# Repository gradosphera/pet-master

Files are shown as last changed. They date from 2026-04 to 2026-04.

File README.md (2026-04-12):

# PET-Мастер

vlcsnap-2026-04-11-18h14m20s894

Образовательно-экологический проект по созданию настольного пултрузионного станка, который превращает использованные PET-бутылки в качественный филамент для 3D-печати.

Технология локальной переработки пластиковой тары в расходный материал для 3D-печати

[Паспорт проекта](/Паспорт%20проекта.md)
<br>
[Программа мастер-классов](/Программа%20мастер-классов.md)
<br>
[Технологическая карта](/Технологическая%20карта.md)
<br>
[Инструкция волонтера](/Инструкция%20волонтера.md)
<br>
[Протокол испытаний](/Протокол%20испытаний.md)
<br>
[Руководство по подбору ширины ленты](/Руководство%20по%20подбору%20ширины%20ленты.md)
<br>
[Регламент по технике безопасности](/Регламент%20по%20технике%20безопасности%20.md)
<br>
[Спецификация комплектующих](/Спецификация%20комплектующих.md)
<br>
[Список комплектующих](/Список%20комплектующих.md)
<br>
[Необходимый инструмент для сборки](/Необходимый%20инструмент%20для%20сборки.md)
<br>
[Схема электрическая принципиальная](/Схема%20электрическая%20принципиальная.md)

## 1. Резюме проекта

Проект «PET-Мастер» — это открытая образовательная и технологическая платформа, направленная на популяризацию вторичной переработки среди детей, школьников и студентов. Мы предлагаем доступную технологию создания настольного пултрузионного станка, который позволяет превращать использованные PET-бутылки в качественный филамент для 3D-принтера.

## 2. Актуальность и экологическая миссия

Ежегодно в мире производятся миллионы тонн PET-тары, лишь малая часть которой перерабатывается. 3D-печать, в свою очередь, требует дорогостоящего пластика.

«PET-Мастер» решает две задачи:

- Экология: Снижение количества мусора за счет локальной переработки пластика.
- Образование: Обучение основам инженерного дела, электроники и эко-осознанности через сборку реального устройства.

## 3. Описание технологии

В основе станка лежит метод термической пултрузии. В отличие от сложных промышленных шнековых экструдеров, используется упрощенная, но эффективная схема:

1.  Подготовка сырья: Бутылка очищается и нарезается на ленту шириной 6–10 мм.
2.  Термоформатирование: Лента проходит через нагретый до 210–220°C блок.
3.  Калибровка: Проходя через сопло диаметром 1.75 мм, плоская лента сворачивается в полую трубку, которая по физико-механическим свойствам идентична филаменту.
4.  Тяговый механизм: Червячный редуктор обеспечивает высокий крутящий момент и стабильную скорость протяжки, наматывая готовую нить на катушку.

## 4. Конструктив и концепция собери сам

Станок спроектирован по принципу открытых технологий: большая часть деталей корпуса изготавливается методом 3D-печати.

- Доступность компонентов: Все узлы (подшипники, нагреватели, контроллеры, метизы) доступны на популярных маркетплейсах.
- Формат документации: Чертежи и модели предоставляются в формате STL.
- Инструментарий: Для сборки требуется базовый набор: отвертки, гаечные и шестигранные ключи, паяльник, ножницы и кримпер для обжима контактов, дрель.

## 5. Образовательный потенциал

Проект является идеальным учебным пособием, охватывающим дисциплины:

- Аддитивные технологии: Понимание принципов работы FDM-печати.
- Схемотехника: Подключение PID-регуляторов, двигателей и блоков питания.
- Материаловедение: Изучение свойств полимеров (полиэтилентерефталат).
- Экологическое проектирование: Жизненный цикл продукта и экономика замкнутого цикла.

## 6. Технические характеристики (целевые)

- Тип сырья: ПЭТ-лента (из бутылок).
- Диаметр нити: 1.75 мм (допуск ±0.5 мм).
- Температурный режим: 210–220°C.
- Питание: 220В.
- Скорость производства: зависит от передаточного числа редуктора (в среднем 150–300 мм/мин).

## 7. Комплектация документации

Участники проекта получают доступ к полному пакету материалов:

1.  Спецификация на комплектующие.
2.  Набор STL-файлов для печати корпуса.
3.  Пошаговая инструкция по сборке и калибровке.
4.  Стандарты качества получаемой нити.

---

## Необходимый инструмент для сборки:

1.  Для механики: Набор отверток, гаечные ключи, шестигранные ключи.
2.  Для электрики: Паяльник, кримпер для обжима наконечников, ножницы.
3.  Для калибровки: Шуруповерт или дрель (для работы сверлом 1.7 мм по соплу).

## 📋 Таблица соединений на колодках

| Колодка | Вход | Выход / Потребитель |
| --- | --- | --- |
| №1 (AC 220V) | Сетевое гнездо + Кнопка | Вход Блока Питания 12В |
| №2 (DC 12V)  | Выход Блока Питания | ШИМ-контроллер, Вентилятор, Контроллер температуры |
| №3 (Нагрев)  | Реле контроллера температуры | Нагревательный элемент 50Вт |

## 💡 Важные рекомендации для сборки:

- Изоляция: Все соединения 220В должны быть закрыты термоусадкой или находиться внутри печатного корпуса, недоступного для случайного касания.
- Кримпер: Обязательно используйте обжим наконечников (НШВИ) перед фиксацией проводов в винтовых колодках — это предотвратит искрение и подгорание контактов.
- Полярность: У ШИМ-контроллера и термостата переполюсовка может привести к выходу из строя — проверяйте мультиметром «плюс» и «минус» перед включением.

## 7. Экономика и экологический эффект

## Расчет производственной мощности

Исходя из технических характеристик станка:

- Скорость переработки: 1 пластиковая бутылка (1,5 л) за 35 минут (среднее значение).
- Выход материала: 1 бутылка дает около 25–30 грамм качественного филамента.
- Годовой объем (при средней занятости): При работе станка всего 4 часа в день (учитывая время на сборку, отладку и подготовку ленты), проект позволяет перерабатывать около 2 500 бутылок в год.
- Итоговый продукт: Это эквивалентно 65–75 кг готового филамента для 3D-печати.

## Потенциальная выгода для местного сообщества

Локальная переработка на базе «PET-Мастера» превращает отходы в ценный ресурс:

1.  Экономия бюджета: Стоимость 75 кг заводского филамента составляет около 150 000 – 200 000 рублей. Проект позволяет сообществу (детскому дому, школе, фаблабу, ТСЖ) получать этот материал практически бесплатно.
2.  Стимул к раздельному сбору: Когда жители видят, как выброшенная бутылка превращается в полезную деталь (игрушку, инструмент, запчасть), ценность раздельного сбора становится осязаемой. Это формирует культуру «ноль отходов».
3.  Локальная очистка: Переработка 2 500 бутылок одним станком — это очистка территории небольшого парка или двора от видимого пластикового мусора в течение года.

## 8. Государственное и стратегическое значение

Проект «PET-Мастер» полностью соответствует вектору развития Российской Федерации:

- Национальный проект «Экологическое благополучие»: инициативы в сфере экономики замкнутого цикла.
- Цели-2030: Согласно государственным задачам, к 2030 году 100% твердых коммунальных отходов (ТКО) должны проходить сортировку, а не менее 25% — возвращаться в оборот как вторсырье. Наш проект является инструментом «низовой» цифровой экологии, позволяющим достигать этих показателей на уровне домохозяйств и образовательных центров.

## 9. Лицензирование и открытый доступ

Проект придерживается принципов открытого обмена знаниями:

- Документация и репозиторий: Текст «PET-Мастер», инструкции и схемы распространяются на условиях Общественного достояния (Public Domain). Любой человек или организация могут свободно использовать, копировать и распространять эти данные.
- 3D-модели корпуса: Файлы в формате STL распространяются под лицензией Creative Commons Некоммерческая (CC BY-NC).
- Разрешено: копировать, распространять, изменять и создавать производные работы.
  - Ограничение: использование моделей в коммерческих целях (продажа готовых станков или платных чертежей) запрещено. Это гарантирует, что проект останется доступным для образовательных и экологических сообществ.

---

PET-Мастер: Мы не просто перерабатываем пластик — мы печатаем будущее своими руками.
[Репозиторий проекта: https://github.com/gradosphera/pet-master

---

Лицензионное примечание: Данный документ является частью документации проекта «PET-Мастер» и распространяется на условиях Общественного достояния (Public Domain). Модели корпуса защищены лицензией CC BY-NC.

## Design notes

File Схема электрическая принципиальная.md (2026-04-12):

# Электрическая схема соединений станка

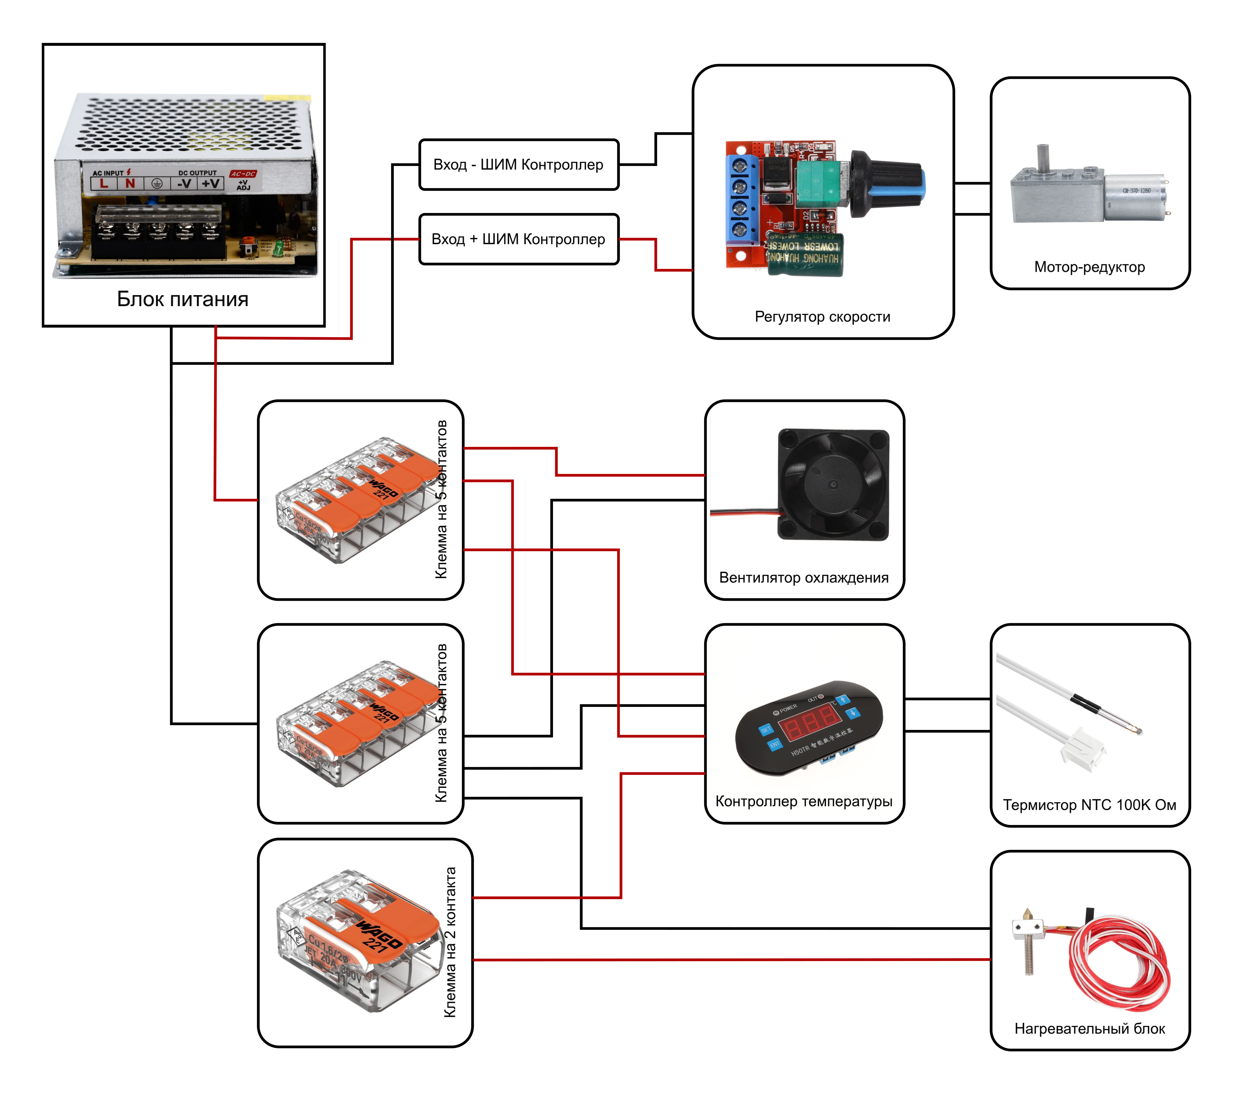
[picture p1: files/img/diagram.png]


```mermaid

flowchart
    %% Источник питания
    PSU[Блок питания 12В]

    %% Узлы распределения (Шины)
    PLUS{+ 12V}
    MINUS{- GND}

    PSU --> PLUS
    PSU --> MINUS

    %% Линия 1: Контроллер скорости и мотор
    subgraph Motor_Circuit [Линия мотора]
        PLUS --> PWM_IN_P[ШИМ Контроллер: Вход +]
        MINUS --> PWM_IN_M[ШИМ Контроллер: Вход -]
        PWM_IN_P --- PWM[Регулятор скорости]
        PWM_IN_M --- PWM
        PWM --> MOTOR[Мотор-редуктор]
    end

    %% Линия 2: Колодка и вентилятор
    subgraph Cooling_Circuit [Линия обдува]
        PLUS --> BUS_BAR[Электрическая колодка]
        BUS_BAR --> FAN_P[Вентилятор +]
        MINUS --> FAN_M[Вентилятор -]
    end

    %% Линия 3: Температурный контроль
    subgraph Heating_Circuit [Линия нагрева]
        %% Питание самого контроллера
        PLUS --> TEMP_POWER_P[Термоконтроллер: Питание +]
        MINUS --> TEMP_POWER_M[Термоконтроллер: Питание -]

        TEMP_POWER_P --- TEMP_CTRL[Контроллер температуры]
        TEMP_POWER_M --- TEMP_CTRL

        %% Цепь управления нагревом (Реле)
        PLUS --> RELAY_IN[Контакт реле K0]
        RELAY_IN --- RELAY[Реле контроллера]
        RELAY --- RELAY_OUT[Контакт реле K1]
        RELAY_OUT --> HEATER_P[Нагревательный модуль +]
        MINUS --> HEATER_M[Нагревательный модуль -]

        %% Датчик
        THERMISTOR[Терморезистор] --> TEMP_CTRL
    end

    %% Стилизация
    style PSU fill:#f9f,stroke:#333,stroke-width:4px
    style PLUS fill:#ff9999
    style MINUS fill:#9999ff
    style HEATER_P fill:#ff4444
    style MOTOR fill:#99ff99

```

## 1. Входная цепь (Сетевое напряжение 220В)

- Питание: Сетевой кабель C7 → Гнездо C8 на корпусе.
- Защита и разрыв: От гнезда C8 фазный провод идет на Тумблер (кнопку).
- Распределение: После кнопки провода (L и N) идут на Первую колодку (входную). К ней подключается вход вашего Блока Питания (БП) 12В.

## 2. Низковольтный блок (12В) — Распределение через клеммы

Выход с Блока Питания (+12В и -12В) подается на Вторую колодку (шину питания). Отсюда ток расходится на три узла:

А. Узел протяжки (Линия мотора):

1.  От 12В-колодки питание идет на вход ШИМ (PWM) контроллера (контакты Power+ / Power-).
2.  Выход ШИМ-контроллера (Motor+ / Motor-) подключается напрямую к Червячному мотор-редуктору.
3.  Примечание: Если вал крутится не в ту сторону, просто поменяйте провода мотора местами.

Б. Узел охлаждения:

1.  Вентилятор 40х40 подключается напрямую к 12В-колодке. Он должен работать постоянно при включении станка для охлаждения электроники и предотвращения расплавления корпуса.

В. Узел нагрева (Линия термостата):

1.  Питание 12В с колодки подается на контакты питания Контроллера температуры H50TR.
2.  Датчик температуры (Термистор NTC 100K) подключается в выделенный разъем на контроллере.
3.  Нагревательный блок: Один провод нагревателя идет к «+12В» на колодке, а второй — через Реле (выходные контакты) контроллера температуры к «-12В» (GND). Это позволит контроллеру разрывать цепь при достижении нужной температуры.

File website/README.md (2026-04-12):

# Сайт документации PET-Мастер

Репозиторий проекта: [github.com/gradosphera/pet-master](https://github.com/gradosphera/pet-master).

**Тема оформления:** в шапке кнопка переключает светлую и тёмную (фон `#1e2337`, зелёные акценты). Выбор сохраняется в `localStorage` (`pet-master-theme`).

## Локальный просмотр (папка `website/` внутри репозитория)

Из **корня** репозитория:

```bash
python -m http.server 8080
```

Откройте: [http://localhost:8080/website/](http://localhost:8080/website/)

Скрипт `js/pet-paths.js` сам подставляет префикс `../` к файлам репозитория (Markdown, CSV, `models/`, `docs/`, `models.zip`).

## GitHub Pages

1. В репозитории: **Settings → Pages → Build and deployment → Source: GitHub Actions**.
2. После push в ветку `main` запускается **Deploy GitHub Pages** (`.github/workflows/deploy-pages.yml`).
3. В корень публикации копируются: содержимое `website/`, все `*.md` из корня, `List_hardware_PET_Master.csv`, `models/`, `docs/`, при наличии — `files/`, а также **`models.zip`** (скрипт `scripts/zip-models.sh`).
4. Сайт: `https://gradosphera.github.io/pet-master/` (или `https://<org>.github.io/pet-master/` в зависимости от владельца).

Локально без подкаталога `/website/` пути **плоские** (`./README.md`, `./docs/...`) — так же работает опубликованная сборка.

## Фото процесса сборки (`files/img/Процесс сборки станка/`)

Сюда кладутся сюжетные **.webp** для страниц сайта (сборка, мастер-классы, работа станка). В HTML используется атрибут `data-pet-src` — URL подставляет `js/repo-links.js`.

## Превью 3D-деталей (`docs/img/`)

Таксономия совпадает с `models/`: **`docs/img/Основание/`**, **`docs/img/Электроника/`**, **`docs/img/Вал намотки/`**.

- Форматы: **`.jpg`** (основной), при отсутствии — **`.png`**.
- Имя файла обычно совпадает с моделью: расширение `.stl` / `.3mf` заменяется на `.jpg`. Для случаев вроде `…16 шт.stl` и `…16 шт..jpg` на странице перебираются варианты.
- В манифесте у категории поле **`imgFolder`** задаёт подкаталог в `docs/img/` (по умолчанию = `title`).
- У записи файла поле **`preview`**: имя файла в этой папке или полный путь `docs/img/…`.

## Архив моделей

```bash
bash scripts/zip-models.sh
```

Создаёт `models.zip` в корне репозитория (или путь первым аргументом). На GitHub Pages тот же архив кладётся в корень сайта; ссылка — на странице **3D-модели**.

## Обновление каталога STL

После добавления файлов в `models/` обновите `website/data/stl-manifest.json`.

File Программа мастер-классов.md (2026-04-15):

# Программа мастер-классов «PET-Мастер: От бутылки до значка»

Цель: Обучение полному циклу рециклинга ПЭТ и популяризация раздельного сбора.
Длительность: 4 занятия по 1.5–2 часа.
Бонусы: Именные значки из «мусора», верифицированные часы на Добро.РФ.

---

## Занятие 1: «Эко-логика и подготовка сырья»

- Теория (20 мин): Проблема ПЭТ в России. Экономика замкнутого цикла. Национальные цели 2030. Разница между PET, HDPE и другими видами пластика.
- Практика (60 мин):
- Сортировка принесенной тары.
- Удаление клея и этикеток.
- Рифтовка: Накачка бутылок через ниппель и выравнивание строительным феном.
- Результат: Подготовленные «ровные» заготовки для нарезки.

## Занятие 2: «Инженерия станка и нарезка ленты»

- Теория (20 мин): Устройство станка «PET-Мастер». Зачем нужен червячный редуктор? Как работает термоконтроллер H50TR.
- Практика (60 мин):
- Измерение толщины стенок бутылок штангенциркулем.
- Настройка встроенного ножа (подбор калибровочных дисков).
- Нарезка ленты (каждый волонтер должен подготовить моток 10–15 метров).
- Результат: Моток ленты, готовый к экструзии.

## Занятие 3: «Экструзия и управление качеством»

- Теория (15 мин): Физика процесса пултрузии. Почему ПЭТ из бутылок тугоплавкий? Разбор ГОСТ Р 59100-2020.
- Практика (70 мин):
- Разогрев станка до 215°C.
- Заправка ленты и запуск мотора.
- Контроль диаметра нити (заполнение протокола испытаний).
- Результат: Катушка готового вторичного филамента.

## Занятие 4: «3D-печать и награждение»

- Теория (15 мин): Настройка слайсера для печати ПЭТ-лентой. Коэффициент потока 130% и высокие температуры (260°C).
- Практика (60 мин):
- Запуск печати значков проекта (логотипы «Зеленый дом» или «Лаборатория переработки»).
- Наблюдение за процессом, разбор типичных ошибок печати.
- Финал (15 мин):
- Вручение значков, напечатанных на глазах волонтеров.
- Проставление волонтерских часов в системе Добро.РФ (через личный кабинет организатора).

---

## Инструкция по Добро.РФ:

1.  Создание мероприятия: Название «Мастер-класс по вторичной переработке ПЭТ-тары».
2.  Тип волонтерства: «Экологическое» или «Научное».
3.  Описание вклада: «Участие в производстве вторичного сырья для аддитивных технологий и ликвидация пластикового загрязнения».
4.  Подтверждение: После занятия организатор сканирует QR-код волонтера или вводит ID для начисления часов.

---

## Оборудование для одного учебного места:

- Станок «PET-Мастер» — 1 шт.
- Строительный фен и насос — 1 шт.
- Штангенциркуль — 1 шт.
- 3D-принтер (с цельнометаллическим хотэндом) — 1 шт. на группу.
- Индивидуальные средства защиты (перчатки).

---

# Программа мастер-классов «PET-Инженер: Мастерская вторичной переработки»

Цель: Сборка 3-х действующих станков (PET-Мастер) для масштабирования проекта и обучения инженерным навыкам.

Срок реализации: 4 недели (1 занятие в неделю по 2-2.5 часа + самостоятельная работа).

Место: МОУ "Инженерная школа города Комсомольска-на-Амуре"

Бонусы: Верифицированные часы на Добро.РФ, статус «PET-Инженер».

## Календарный план занятий

| Неделя | Тема занятия | Основные задачи | Результат этапа |
| --- | --- | --- | --- |
| 1 | Архитектура и электроника | Разбор схем управления (Терморегулятор/Контроллер), пайка, сборка нагревательного блока и датчиков. | Собранный электронный модуль управления. |
| 2 | Механика и 3D-печать | Сборка рамы станка, установка мотор-редуктора. Обсуждение параметров печати деталей. | Сборка корпуса станка. |
| 3 | Протяжка и термоблок | Монтаж сопла, системы нарезки ленты и механизма крепления нити на барабан. Настройка температуры. | Готовая конструкция, готовая к первым тестам. |
| 4 | Калибровка и запуск | Настройка стабильности диаметра нити (1.75 мм), тестовая печать значков из полученного филамента. | 3 готовых станка, переданые в дар школе. |

---

## Ресурсная спецификация (на 3 станка)

Для реализации программы требуется предварительная подготовка в МОУ "Инженерная школа города Комсомольска-на-Амуре":

- 3D-печать комплектующих:
- Время: ~20 часов суммарно.
  - Материал: ~2 кг пластика (рекомендуется PETG для деталей корпуса).
- Электронная база: Цифровые терморегуляторы H50TR, , нагревательные блоки 50W, термисторы, ШИМ-контроллеры, блоки питания 12V.
- Механическая база: Мотор-редукторы 12V 6 об. мин., Сопла (диаметр 0.6 мм), подшипники, профиль 30x30

---

## Методические особенности (Инженерная школа №25)

1.  Интеграция с Инженерной Школой: Школьники могут самостоятельно собрать или доработать станки.
2.  Масштабируемость: Каждый собранный станок становится «производственной единицей» для других школ города.
3.  Практический выход: Ученики школы №25 выступают в роли инженеров-производителей, обеспечивая оборудованием новые площадки проекта «PET-Мастер».

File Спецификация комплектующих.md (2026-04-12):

# Спецификация комплектующих (BOM-лист) проекта «PET-Мастер»

## 1. Электроника и управление нагревом

- Контроллер температуры H50TR (-40~300℃) — 1 шт. (основной блок управления нагревом).
- Нагревательный блок 12В 50Вт (6х20мм) — 1 шт. (элемент для плавления ленты).
- Термистор NTC 100K Ом 3950 (разъем XH2.54-2P) — 1 шт. (датчик температуры).
- ШИМ (PWM) контроллер 5A 90Вт 12В (XK-1074) — 1 шт. (регулировка скорости протяжки).

## 2. Механика и привод

- Червячный мотор-редуктор 12В (8 мм вал, 6 об/мин) — 1 шт. (силовой агрегат тяги).
- Подшипник 608Z — 2 шт. (для плавного вращения катушки/вал).
- Профиль конструкционный алюминиевый 30х30H (300мм) — 2 шт. (основа рамы станка).

## 3. Электрика и коммутация

- Гнездо питания C8 сетевое (10А) — 1 шт. (вход питания на корпусе).
- Сетевой кабель питания С7 (1,5м) — 1 шт. (шнур в розетку).
- Вилка угловая 16А — 1 шт.
- Провод ПВС 3х1,5 — 1 метр.
- Клеммы быстрозажимные (Wago-тип): 2 контакта (1 шт.), 5 контактов (2 шт.).
- Колодка винтовая КЭВ 3-12 (12 пар) — 1 шт.
- Тумблер-кнопка круглый (3А, 16мм) — 1 шт. (включение устройства).
- Вентилятор 40х40х20 12В — 1 шт. (охлаждение электроники и зоны выхода нити).

## 4. Расходники для экструзии

- Сопло латунное 0.6 мм — 3 шт. (используются как эструдер; рассверливаются до 1.75 мм).
- Сверло по металлу 1.7 мм (кобальтовое) — 1 шт. (для калибровки сопла).
- Пластик для 3D-принтера (1кг) — 1 шт. (для печати деталей самого станка).

## 5. Крепежные изделия (Метизы)

- Болты М8: М8х200 (2 шт.), М8х35 (2 шт.), М8х40 (4 шт.).
- Винт специальный: M8x8x120мм (цилиндрическая головка) — 1 шт.
- Винты М3: М3х10 (10 шт.), М3х12 (10 шт.), М3х16 (5 шт.).
- Гайки: М3 (20 шт.), М8 (3 шт.).
- Шайбы: М8 оцинкованные (4 шт.).
- Пластина соединительная 2мм (40х100) — 1 шт. (усиление конструкции).

## 6. Прочее и СИЗ

- Колодка 4м 16Д (3,5кВт) — 1 шт.
- Перчатки трикотажные — 1 пара (защита рук при сборке и работе с горячим блоком).

## Список комплектующих на сборку 1 станка

| Наименование | Количество |
| --- | --- |
| Блок питания 100W 12В | 1 шт |
| Болт М8х200 | 1 шт |
| Болт М8х35 | 2 шт |
| Болт М8х40 | 4 шт |
| Вентилятор 40х40х20 12в | 1 шт |
| Вилка угловая 16А | 1 шт |
| Винт М3х10 | 10 шт |
| Винт М3х12 | 10 шт |
| Винт М3х16 | 5 шт |
| Винт M8x8x120мм, головка: Цилиндрическая | 1 шт |
| Гайка М3 | 20 шт |
| Гайка М8 | 3 шт |
| Гнездо питания C8 сетевое для аппаратуры на корпус 250V 10А | 1 шт |
| Клемма соединительная быстрозажимная на 2 контакта | 1 шт |
| Клемма соединительная быстрозажимная на 5 контактов | 2 шт |
| Колодка 4м 16Д 3,5кВт | 1 шт |
| Колодка КЭВ 3-12 3А 1-2,5мм 12 пар | 1 шт |
| Контроллер температуры H50TR -40~300℃ | 1 шт |
| Нагревательный блок 12В 50w 6х20мм | 1 шт |
| Перчатки трикотажные | 1 шт |
| Пластик для 3D принтера 1кг | 1 шт |
| Пластина соединительная 2мм 40х100 | 1 шт |
| Подшипник 608Z | 2 шт |
| Провод ПВС 3х1,5 | 1 шт |
| Профиль конструкционный 30х30H 300мм | 2 шт |
| Сверло по металлу 1.7 мм кобальтовое | 1 шт |
| Сетевой кабель питания С7 1,5м | 1 шт |
| Сопло латунное для 3D принтера 0.6 мм | 3 шт |
| Термистор NTC 100K Ом 3950 с разъемом XH2.54-2P без оболочки (капля) | 1 шт |
| Тумблер кнопка выключатель круглый 3А 250В 2pin (Диаметр 16мм) | 1 шт |
| Уголок 40х40х20 мм | 1 шт |
| Червячный мотор-редуктор постоянного тока 12 В 8 мм 6 об/мин | 1 шт |
| Шайба оцинкованная М8 | 4 шт |
| ШИМ PWM контроллер регулятор скорости двигателя постоянного тока DC4.5V-35V 5A 90 Вт 12В с выключателем XK-1074 | 1 шт |

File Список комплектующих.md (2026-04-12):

# Список комплектующих

Это чек-лист для закупки на маркетплейсах.

| Изображение | Категория  | Наименование компонента | Кол-во  | Примечание |
| --- | --- | --- | --- | --- |
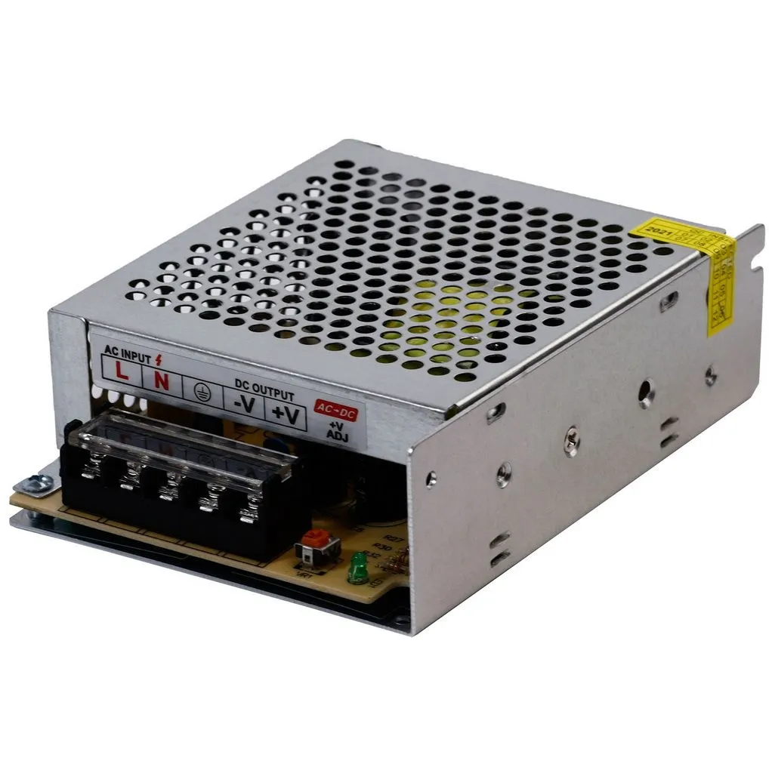
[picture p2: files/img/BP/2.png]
|  | Электрика  | Блок питания 12В 100Вт | 1 шт | Питание |
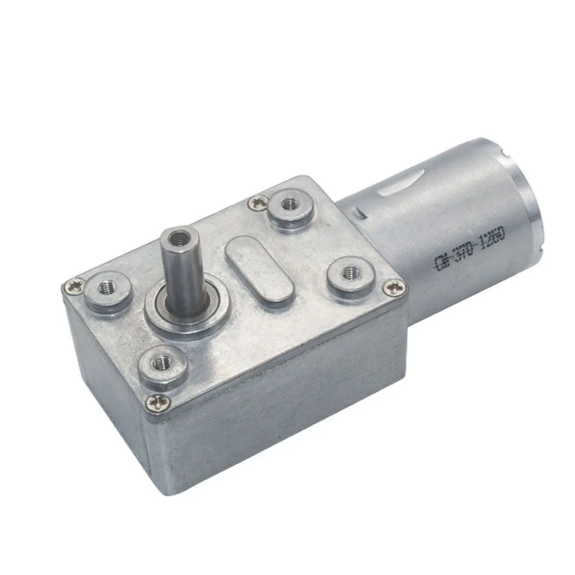
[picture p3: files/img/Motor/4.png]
|  | Привод | Червячный мотор-редуктор 12В (8 мм вал, 6 об/мин) | 1 шт | Силовой узел тяги |
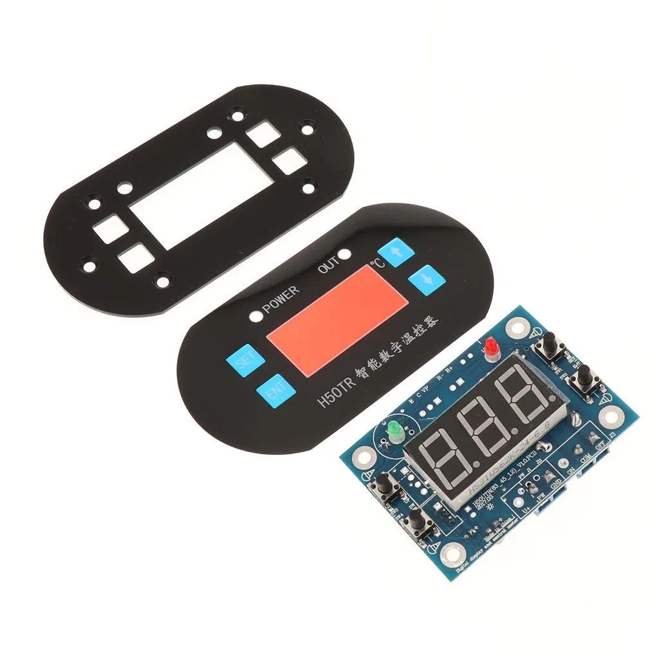
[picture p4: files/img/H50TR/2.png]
|  | Нагрев | Термоконтроллер H50TR (-40~300℃) | 1 шт | Управление температурой |
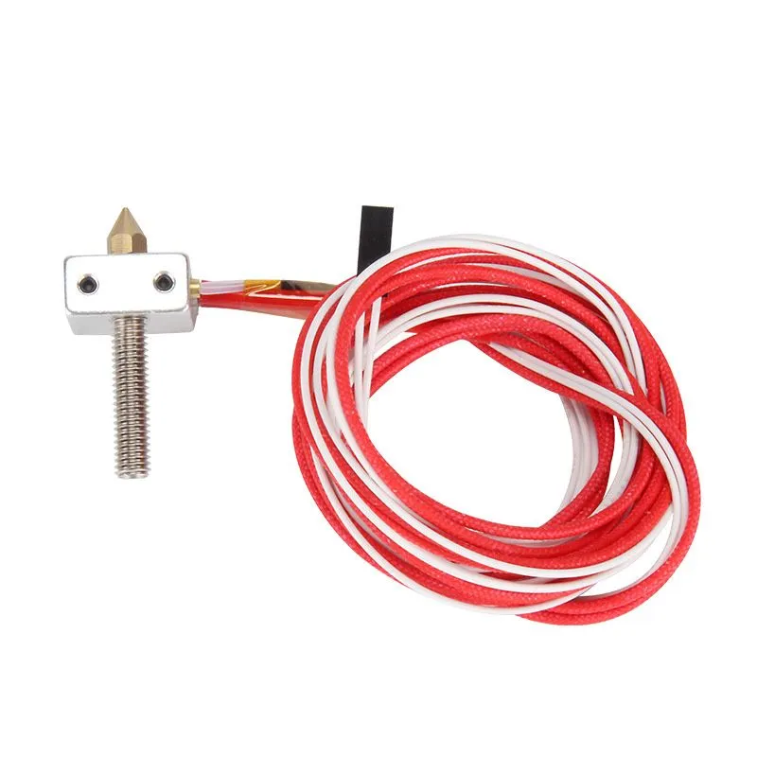
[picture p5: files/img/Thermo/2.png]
|  | Электрика  | Нагревательный блок 12В до 50Вт (6х20мм) | 1 шт | Элемент плавления |
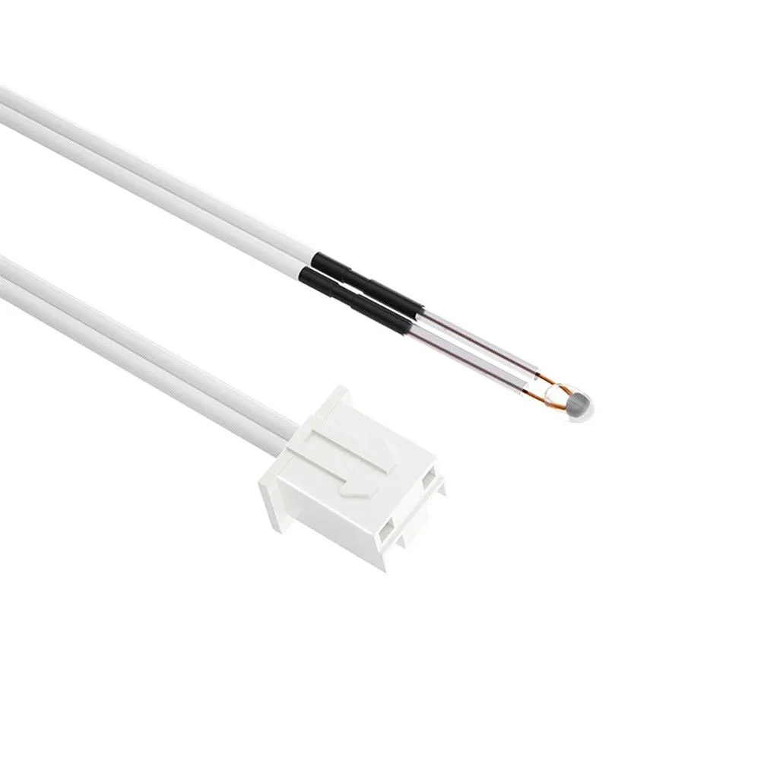
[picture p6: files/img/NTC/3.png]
|  | Электрика  | Термистор NTC 100K 3950 (XH2.54-2P) | 1 шт | Датчик температуры |
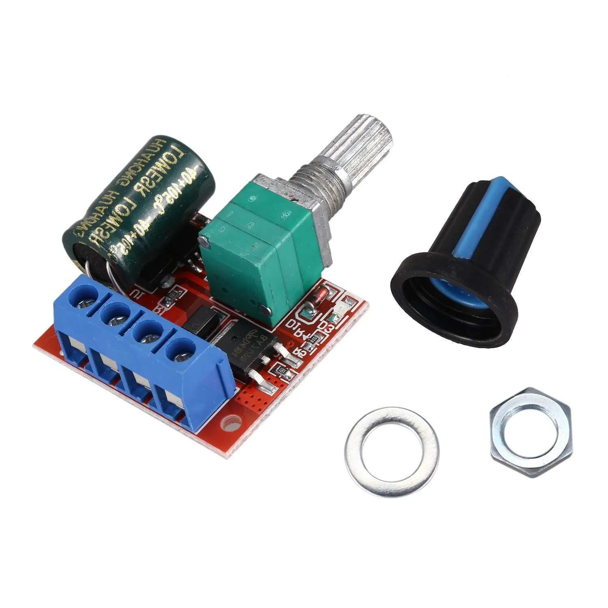
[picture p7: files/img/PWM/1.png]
|  | Управление | ШИМ (PWM) контроллер 5A 90Вт 12В | 1 шт | Регулятор скорости намотки |
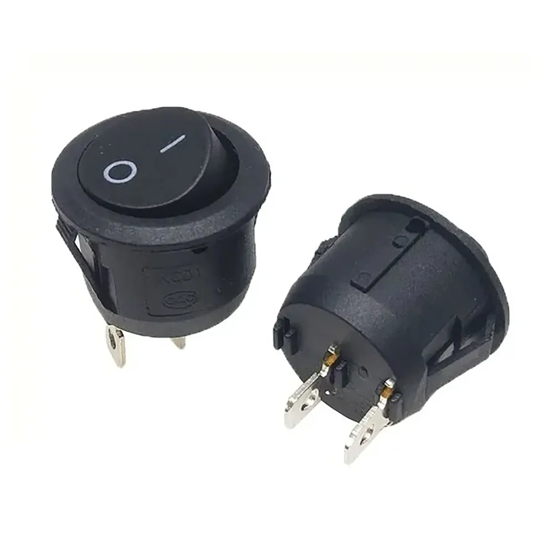
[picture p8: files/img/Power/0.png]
|  | Электрика  | Тумблер-кнопка круглая (3А, 16мм) | 1 шт | Включение питания |
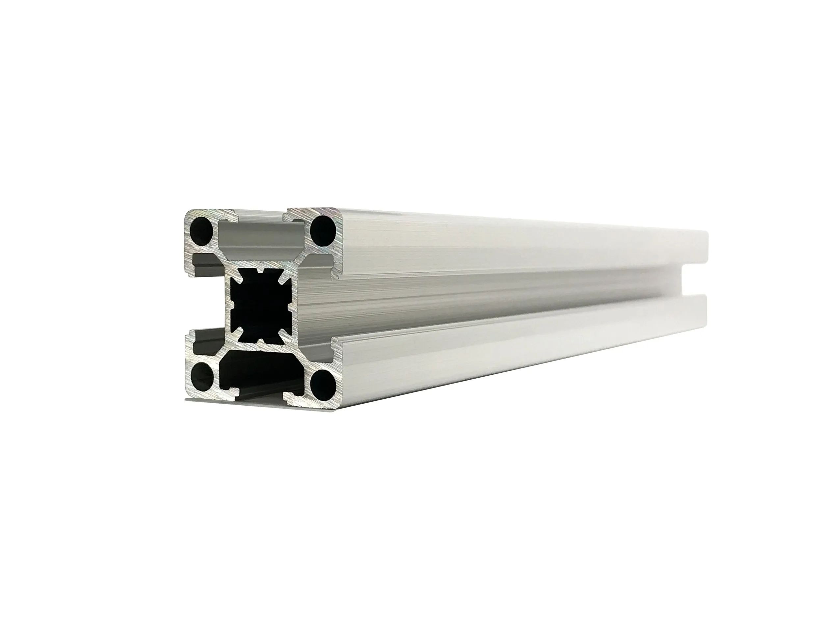
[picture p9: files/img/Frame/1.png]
|  | Рама | Профиль алюминиевый конструкционный 30х30 (300мм) | 2 шт | Несущий каркас |
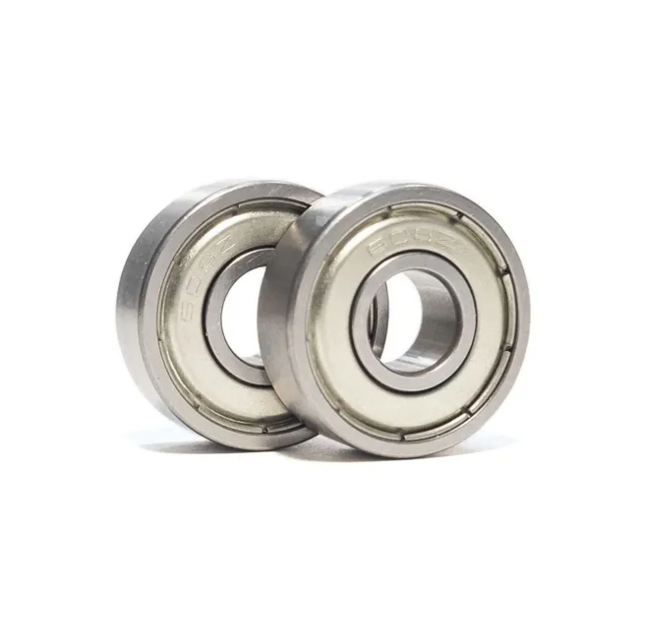
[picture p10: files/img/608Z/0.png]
|  | Вал | Подшипник 608Z | 2 шт | Для вала катушки |
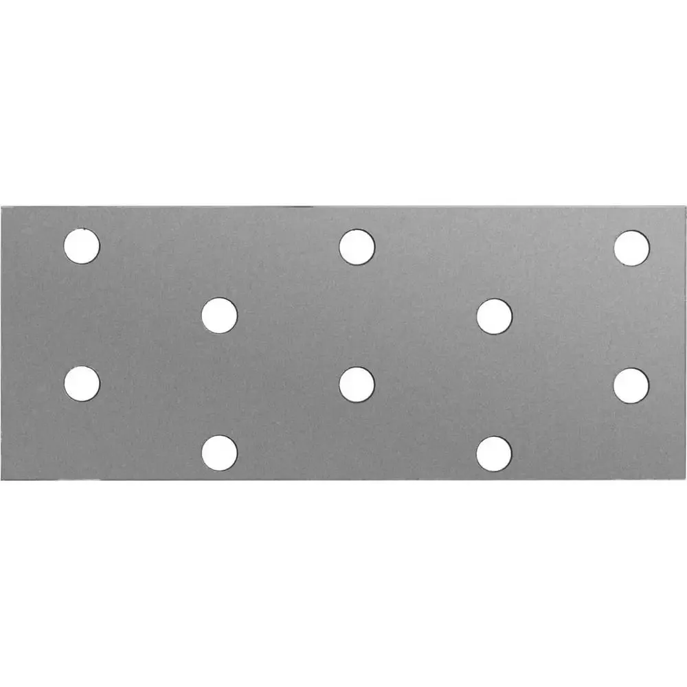
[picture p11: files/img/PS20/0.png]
|  | Нагрев | Пластина соединительная 2мм (40х100) | 1 шт | Усиление узлов |
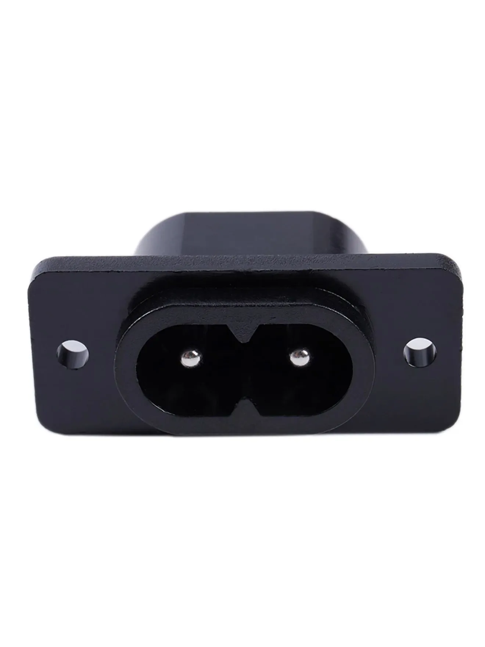
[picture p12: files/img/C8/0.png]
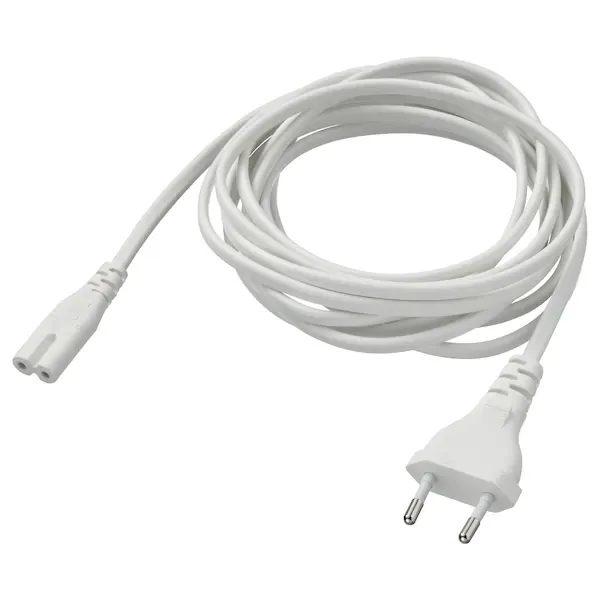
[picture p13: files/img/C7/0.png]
|  | Электрика  | Гнездо сетевое C8 + Кабель питания C7 (1.5м) | 1 компл | Вход 220В |
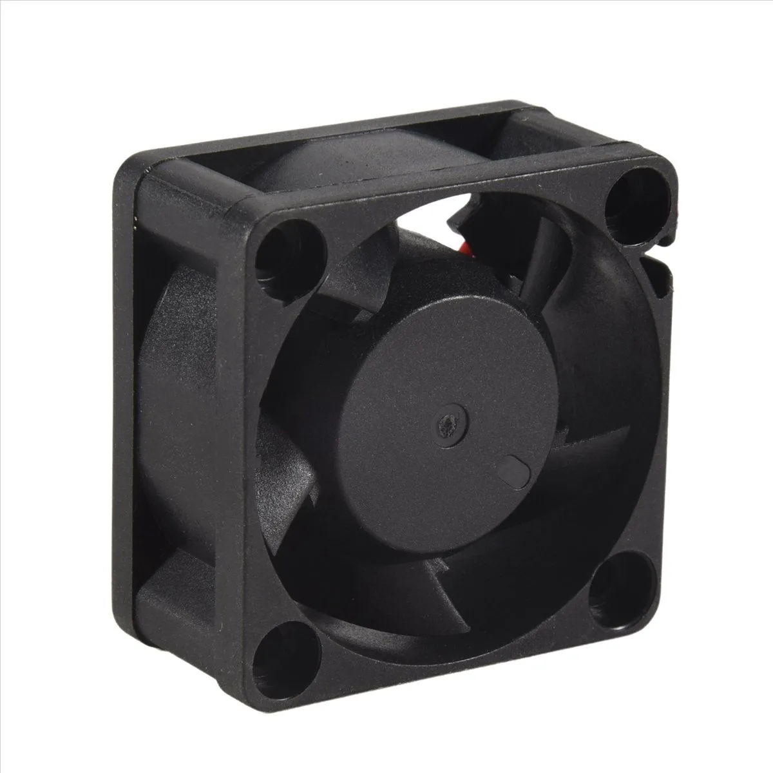
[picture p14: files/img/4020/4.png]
|  | Электрика  | Вентилятор 40х40х20 12В | 1 шт | Охлаждение электроники |
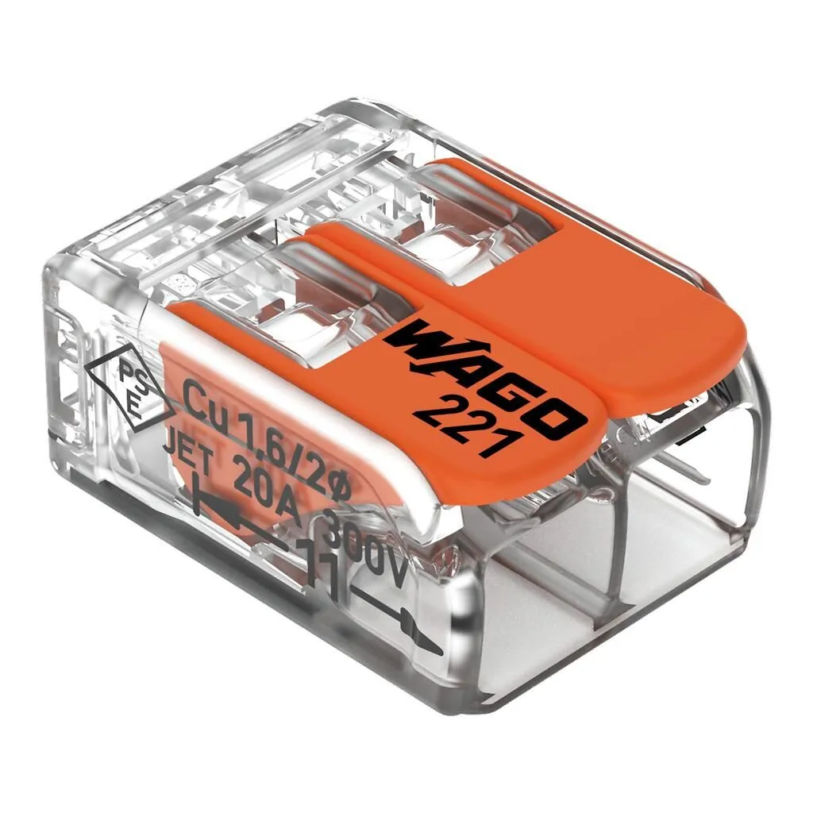
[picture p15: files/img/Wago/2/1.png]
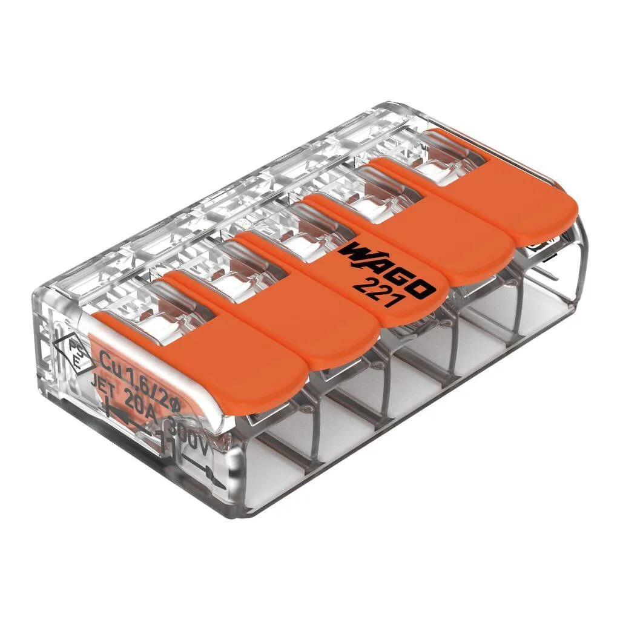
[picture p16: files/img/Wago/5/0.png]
|  | Электрика  | Клеммы быстрозажимные (2 и 5 контактов) | 3 шт | Для монтажа без пайки |
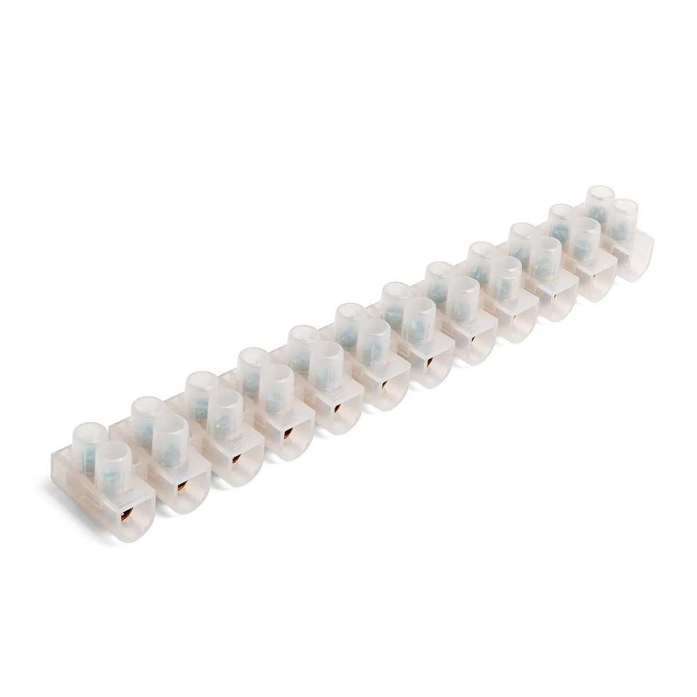
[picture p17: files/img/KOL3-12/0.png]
|  | Вал | Колодка винтовая КЭВ 3-12 | 1 шт | Распределение питания |
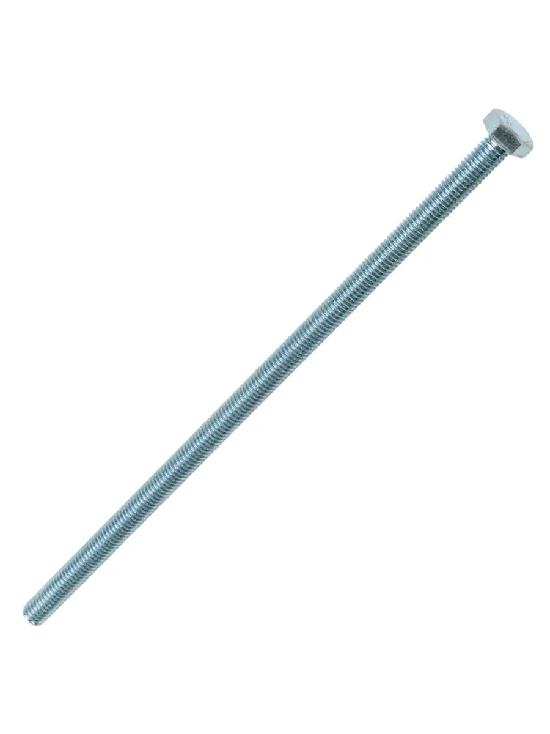
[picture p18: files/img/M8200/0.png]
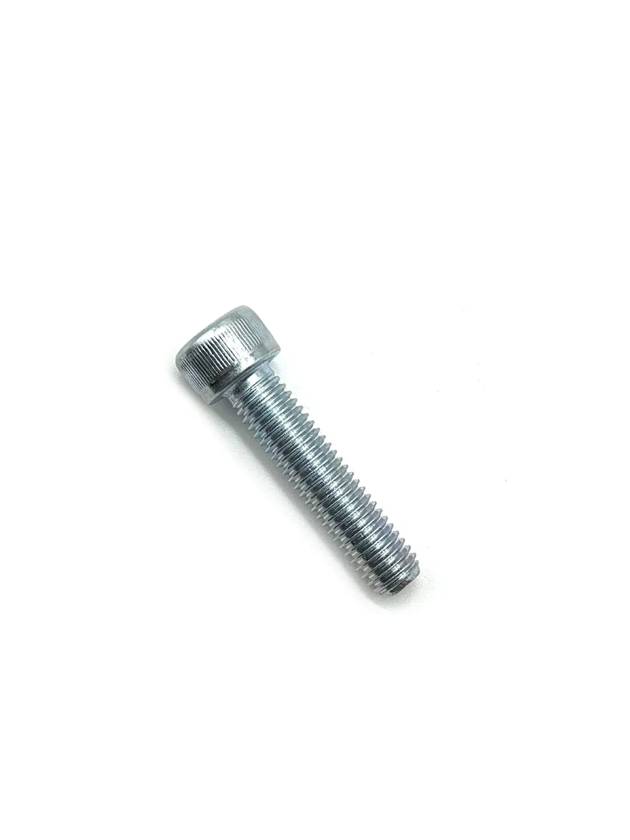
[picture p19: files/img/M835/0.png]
|  | Крепеж | Болт М8 (200мм — 1шт, 35мм — 2шт, 40мм — 4шт) | 8 шт | Основная сборка |
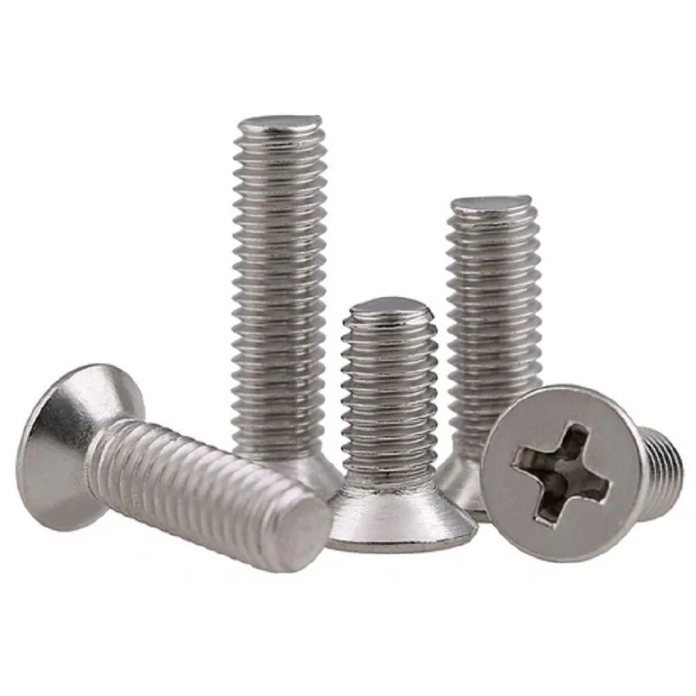
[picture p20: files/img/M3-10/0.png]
|  | Корпус | Винты М3 (10, 12, 16 мм) + Гайки М3 | 1 компл | Для печатных деталей |
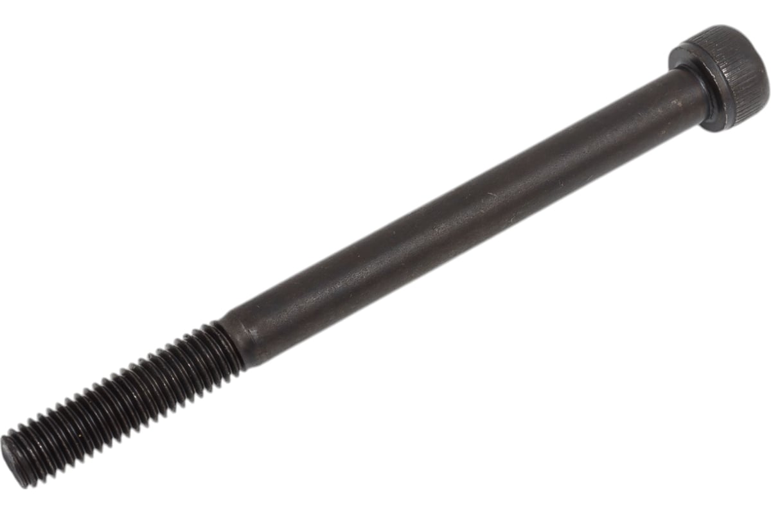
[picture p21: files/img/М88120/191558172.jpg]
|  | Вал | Винт M8x8x120мм (цилиндр. головка) | 1 шт | Ось барабана |
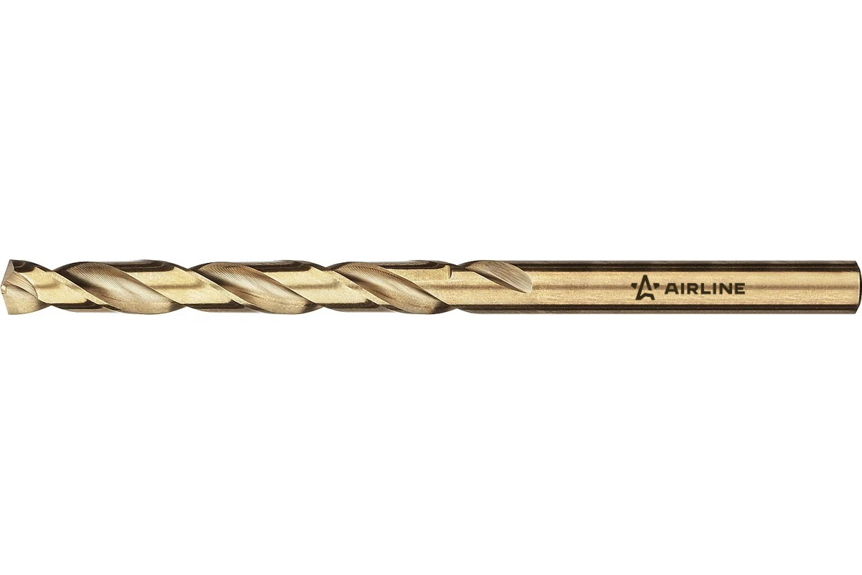
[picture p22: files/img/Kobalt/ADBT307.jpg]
|  | Инструмент | Сверло кобальтовое 1.7 мм | 1 шт | Рассверловка сопла 0.6 мм  |
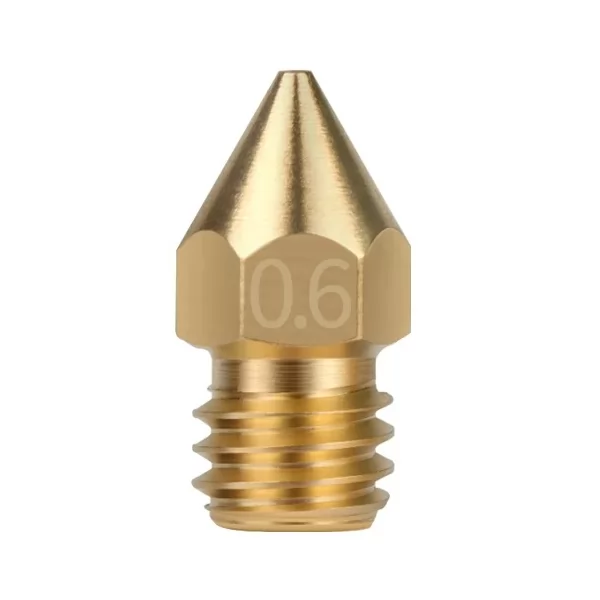
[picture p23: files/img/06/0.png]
|  | Нагрев | Сопло латунное 0.6 мм | 3 шт | Заготовки |
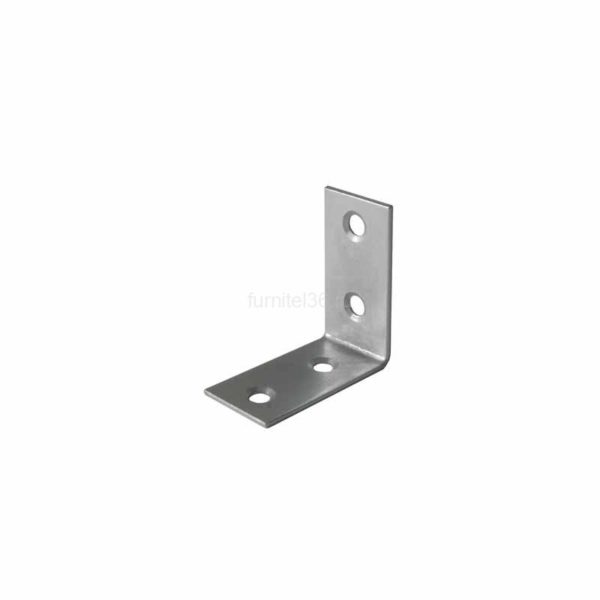
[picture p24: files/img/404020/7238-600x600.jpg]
|  | Рама | Уголок 40х40х20 мм | 1 шт | Несущий каркас |
|  | Расходники | Пластик для 3D печати (1 кг) | 1 шт | Для печати корпуса |

[Полный список оборудования](/List_hardware_PET_Master.csv)

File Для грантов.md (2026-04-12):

# Для грантов: «PET-Мастер»

Технология локальной переработки пластиковой тары в расходный материал для 3D-печати

## 1. Резюме проекта

Проект «PET-Мастер» — это открытая образовательная и технологическая платформа, направленная на популяризацию вторичной переработки среди детей, школьников и студентов. Мы предлагаем доступную технологию создания настольного пултрузионного станка, который позволяет превращать использованные PET-бутылки в качественный филамент для 3D-принтера.

## 2. Актуальность и экологическая миссия

Ежегодно в мире производятся миллионы тонн PET-тары, лишь малая часть которой перерабатывается. 3D-печать, в свою очередь, требует дорогостоящего пластика.
«PET-Мастер» решает две задачи:

- Экология: Снижение количества мусора за счет локальной переработки пластика «на месте».
- Образование: Обучение основам инженерного дела, электроники и эко-осознанности через сборку реального устройства.

## 3. Описание технологии

В основе станка лежит метод термической пултрузии. В отличие от сложных промышленных шнековых экструдеров, «PET-Мастер» использует упрощенную, но эффективную схему:

1.  Подготовка сырья: Бутылка очищается и нарезается на ленту шириной 6–10 мм.
2.  Термоформатирование: Лента проходит через нагретый до 210–220°C блок (хотэнд).
3.  Калибровка: Проходя через сопло диаметром 1.75 мм, плоская лента сворачивается в полую трубку, которая по физико-механическим свойствам идентична заводскому филаменту.
4.  Тяговый механизм: Червячный редуктор обеспечивает высокий крутящий момент и стабильную скорость протяжки, наматывая готовую нить на катушку.

## 4. Конструктив и концепция Сделай сам

Станок спроектирован по принципу открытых технологий: большая часть деталей корпуса изготавливается методом 3D-печати.

- Доступность компонентов: Все узлы (подшипники, нагреватели, контроллеры, метизы) доступны на популярных маркетплейсах.
- Формат документации: Чертежи и модели предоставляются в формате STL.
- Инструментарий: Для сборки требуется базовый набор: отвертки, гаечные и шестигранные ключи, паяльник, ножницы и кримпер для обжима контактов.

## 5. Образовательный потенциал

Проект «PET-Мастер» является идеальным учебным пособием, охватывающим дисциплины:

- Аддитивные технологии: Понимание принципов работы FDM-печати.
- Схемотехника: Подключение PID-регуляторов, двигателей и блоков питания.
- Материаловедение: Изучение свойств полимеров (полиэтилентерефталат).
- Экологическое проектирование: Жизненный цикл продукта и экономика замкнутого цикла.

## 6. Технические характеристики (целевые)

- Тип сырья: ПЭТ-лента (из бутылок).
- Диаметр нити: 1.75 мм (допуск ±0.05 мм).
- Температурный режим: 210–220°C.
- Питание: 12В / 24В.
- Скорость производства: зависит от передаточного числа редуктора (в среднем 150–300 мм/мин).

## 7. Комплектация документации

Участники проекта получают доступ к полному пакету материалов:

1.  Спецификация (BOM-лист) со ссылками на комплектующие.
2.  Набор STL-файлов для печати корпуса.
3.  Пошаговая инструкция по сборке и калибровке.
4.  Стандарты качества получаемой нити.

---

PET-Мастер — это путь от пластикового мусора под ногами к новым инженерным шедеврам на вашем столе.

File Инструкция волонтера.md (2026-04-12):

# Инструкция волонтера проекта «PET-Мастер»

## 1. Общие положения

Волонтер проекта — это активный участник экологического движения, который помогает превращать пластиковые отходы в полезный ресурс. Работа включает в себя как теоретическое обучение, так и практическую работу с оборудованием.

## 2. Задачи волонтера (Основные обязанности)

- Сбор и сортировка: Прием ПЭТ-тары, проверка маркировки (цифра «1» в треугольнике), удаление крышек и этикеток.
- Подготовка: Работа с насосом и строительным феном для выравнивания стенок бутылок.
- Нарезка ленты: Эксплуатация безопасного бутылкореза для подготовки сырья.
- Контроль производства: Наблюдение за работой пултрузионного станка, контроль температуры и равномерности намотки нити.
- Просвещение: Рассказ посетителям лаборатории о важности экономики замкнутого цикла.

## 3. Правила техники безопасности (Обязательно к исполнению!)

- Работа с нагревом: Не касаться латунного сопла и нагревательного блока станка (температура 215°C).
- Средства защиты: Обязательное использование защитных перчаток при работе с феном и горячим пластиком.
- Острые предметы: Быть предельно осторожным при замене лезвий в модуле ножа.
- Электрика: Не оставлять включенные приборы (фен, станок, принтер) без присмотра. При обнаружении запаха гари немедленно выключить тумблер.

## 4. Алгоритм получения волонтерских часов

1.  Регистрация: Быть зарегистрированным на мероприятие через платформу Добро.РФ.
2.  Чек-ин: В начале смены отметиться у координатора проекта (Платформа Добро РФ).
3.  Норматив: Произвести вклад в установленное время (1.5–2 часа) и выполнить производственный цикл (подготовка + нарезка + экструзия).
4.  Чек-аут: В конце смены получить подтверждение часов в личном кабинете.

## 5. Этический кодекс волонтера «Зеленого дома»

- Бережно относиться к оборудованию, созданному сообществом.
- Соблюдать чистоту на рабочем месте (собирать обрезки пластика в контейнер для вторсырья).
- Помогать новичкам в освоении технологии.

## 6. Система поощрений

- Начисление верифицированных волонтерских часов (учитываются при поступлении в вузы и в конкурсах).
- Право на получение фирменного значка, напечатанного из переработанного пластика, созданного собственными руками.
- Доступ к базе знаний по 3D-печати и современной переработке.

---

Твой вклад — это реальный шаг к экологическому благополучию страны к 2030 году!

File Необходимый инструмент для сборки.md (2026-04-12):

# 🛠 Необходимый инструмент для сборки:

1.  Для механики: Набор отверток, гаечные ключи, шестигранные ключи.
2.  Для электрики: Паяльник, кримпер для обжима наконечников, ножницы, отвертки.
3.  Для калибровки: Шуруповерт или дрель (для работы сверлом 1.7 мм по соплу), плоскогубцы, гаечные ключи.

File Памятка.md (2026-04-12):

# 🛠 ПАМЯТКА ВОЛОНТЕРА «PET-МАСТЕР»

## ♻️ ЭТАПЫ РАБОТЫ (Краткий гид)

1.  ИНСПЕКЦИЯ: Проверь маркировку (только PET 01). Удали клей и грязь.
2.  ПОДГОТОВКА: Накачай бутылку (до 2 атм) и прогрей феном до гладкости.
3.  НАРЕЗКА: Установи ширину по таблице толщин. Нарежь ровную ленту.
4.  ЭКСТРУЗИЯ: Прогрей станок до 215°C. Запусти мотор. Следи за диаметром!
5.  ПЕЧАТЬ: Загрузи нить в 3Д принтер (Настройки: 260°C / Поток 135%).

---

## ⚠️ ПРАВИЛА БЕЗОПАСНОСТИ (ВАЖНО!)

- ГОРЯЧО! Сопло станка и хотэнд принтера разогреты до 215–260°C. Не касайся их руками!
- БЕРЕГИ ГЛАЗА И РУКИ: Работай в перчатках при использовании фена. Будь осторожен с острым ножом-бутылкорезом.
- НЕ ОСТАВЛЯЙ БЕЗ ПРИСМОТРА: Уходя, убедись, что нагрев и моторы выключены.
- ВЕНТИЛЯЦИЯ: Убедись, что охлаждающий вентилятор на корпусе работает.

---

## 🌟 ТВОИ БОНУСЫ

- ЧАСЫ В ДОБРО.РФ: Не забудь отметиться у координатора для начисления часов.
- МЕРЧ ИЗ МУСОРА: Забери свой уникальный значок, напечатанный из твоей нити.
- ЗНАНИЯ: Ты теперь профи в экономике замкнутого цикла!

---

## 📏 ТАБЛИЦА БЫСТРОЙ НАСТРОЙКИ

| Толщина бутылки | Ширина ленты |
| --- | --- |
| 0.25 мм (Тонкая)  | 9.6 мм |
| 0.30 мм (Средняя) | 8.0 мм |
| 0.35 мм (Плотная) | 6.9 мм |

---

«Мы не просто перерабатываем пластик — мы создаем будущее!»
Проект соответствует нацпроекту «Экологическое благополучие»

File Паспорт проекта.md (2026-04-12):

# Паспорт проекта: «PET-Мастер»

Настольный комплекс локальной переработки ПЭТ-тары в инженерный филамент

## 1. Состав проектной документации

Полный пакет материалов проекта включает:

1.  PET-Мастер: Идеология, экологическое обоснование и соответствие нацпроектам.
2.  Спецификация (BOM-лист): Полный перечень комплектующих со ссылками на маркетплейсы.
3.  Сборочный чертеж и STL-библиотека: Файлы для 3D-печати корпуса и узлов (Лицензия CC BY-NC).
4.  Схема электрическая принципиальная: Карта соединений (220В / 12В).
5.  Технологическая карта: Пошаговая инструкция «От бутылки до катушки».
6.  Таблица калибровки: Матрица подбора ширины ленты (0.2мм – 0.4мм).
7.  Регламент ТБ: Инструкция по безопасной работе с электроприборами и нагревом.
8.  Протокол испытаний: Шаблон контроля качества готовой нити.

---

## 2. Краткое описание проекта

«PET-Мастер» — это образовательно-экологическая инициатива по созданию настольного пултрузионного станка. Устройство позволяет в домашних или учебных условиях превращать использованные ПЭТ-бутылки в качественный филамент для 3D-печати, используя метод термической калибровки ленты.

## Технические особенности:

- Привод: Червячный мотор-редуктор (12В, 6 об/мин), обеспечивающий стабильную тягу.
- Нагрев: Нагревательный блок 50Вт с контроллером H50TR (рабочая зона 210–220°C).
- Интегрированный нож: Модуль с калибровочными дисками и лезвием для высокоточной нарезки ленты перед экструзией.
- Корпус: Гибридная конструкция из алюминиевого профиля 30х30 и деталей, напечатанных на 3D-принтере.

---

## 3. Порядок работы (Технологический цикл)

1.  Подготовка сырья: Очистка бутылки, установка крышки с ниппелем, накачка воздухом и термоусадка строительным феном для выравнивания поверхности.
2.  Нарезка: Замер толщины стенки штангенциркулем → Настройка ширины ножа по таблице → Получение первичной ленты.
3.  Заправка: Пропуск кончика ленты через сопло (0.6 мм, рассверленное до 1.7 мм) и фиксация на приемном барабане.
4.  Экструзия: Разогрев блока до 210°C, включение ШИМ-контроллера, намотка готового прутка.
5.  Печать: Использование полученной нити на 3D-принтере при температуре 255–260°C с коэффициентом потока 130–135%.

---

## 4. Социальная и экологическая значимость

Проект является практическим инструментом реализации Экономики замкнутого цикла и соответствует нацпроекту «Экологическое благополучие»:

- Рециклинг: Один станок способен переработать до 2500 бутылок в год, превращая их в 75 кг ценного полимера.
- Экономика: Снижение затрат на расходные материалы для образовательных фаблабов в 10–15 раз.
- Образование: Глубокое погружение учащихся в инженерные дисциплины (STEM), электронику и экологическое проектирование.
- Локализация: К 2030 году проект помогает достичь целевых показателей по сортировке и переработке ТКО на уровне местных сообществ.

---

## 5. Юридический статус и лицензирование

- Документация и текстовые материалы: Общественное достояние (Public Domain). Свободное использование в любых целях.
- Цифровые модели (STL): Лицензия Creative Commons Attribution-NonCommercial (CC BY-NC). Разрешено изменять и распространять для некоммерческих и образовательных целей.
- Стандарты: Соответствие ГОСТ IEC 60204-1 (безопасность), ГОСТ EN 12100 (проектирование), ГОСТ Р 59100-2020 (качество филамента).

---

Проект «PET-Мастер» готов к масштабированию и внедрению в образовательный процесс.

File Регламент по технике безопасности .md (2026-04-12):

# Регламент по технике безопасности проекта «PET-Мастер»

## 1. Электробезопасность (согласно ГОСТ IEC 60204-1)

- Изоляция соединений: Все токоведущие части 220В (входное гнездо, кнопка, клеммы питания БП) должны быть изолированы термоусадкой или закрыты защитными кожухами.
- Маркировка проводов: Провода должны иметь четкую цветовую дифференциацию (L — фаза, N — ноль, GND — земля/минус).
- Защита от перегрузки: Блок питания должен иметь встроенную защиту от короткого замыкания.
- Целостность изоляции: Перед каждым включением проверяйте сетевой шнур С7 на отсутствие механических повреждений.
- Сухие руки: Категорически запрещается касаться органов управления и разъемов влажными руками.

## 2. Механическая безопасность (согласно ГОСТ EN 12100)

- Защита от порезов: Лезвие встроенного ножа должно быть зафиксировано и закрыто защитными дисками. Замену лезвия производить только при выключенном станке.
- Опасность затягивания: При работе мотор-редуктора запрещается касаться руками вращающегося барабана и червячной передачи. Соберите длинные волосы и заправьте свободную одежду.
- Устойчивость: Станок должен быть жестко закреплен на горизонтальной поверхности (столе) на предусмотренных в корпусе мягких ножках.

## 3. Термическая безопасность

- Зона нагрева: Нагревательный блок (хотэнд) разогревается до 215°C. Контакт с ним вызывает мгновенный ожог.
- СИЗ: Используйте трикотажные перчатки при заправке ленты в сопло и при работе со строительным феном.
- Охлаждение: Не выключайте вентилятор 40х40 сразу после окончания работы. Дайте станку поработать вхолостую 2–3 минуты для охлаждения корпуса.
- Пожарная безопасность: Никогда не оставляйте включенный станок без присмотра. Рядом с рабочим местом не должно быть легковоспламеняющихся жидкостей и бумаг.

## 4. Работа с давлением (подготовка бутылок)

- Контроль давления: При накачке бутылки насосом не превышайте давление 2–3 атм. Избыточное давление может привести к разрыву пластика.
- Безопасный прогрев: При использовании строительного фена держите его на расстоянии 10–15 см от бутылки. Не направляйте струю горячего воздуха на руки или на ниппель.

## 5. Контроль качества (согласно ГОСТ Р 59100-2020)

Для обеспечения стандарта качества выходной нити (филамента):

- Чистота сырья: Попадание клея или грязи в сопло ведет к деградации полимера и нарушению структуры нити.
- Калибровка: Проверяйте диаметр прутка штангенциркулем каждые 5–10 метров. Допуск по ГОСТ — не более ±0.05 мм.
- Визуальный контроль: Нить должна быть однородной, без пузырьков воздуха (признак влажного пластика) и нагара.

---

## Инструкция «Перед стартом»:

1.  Надень защитные перчатки.
2.  Проверь затяжку гаек на ноже.
3.  Убедись, что вентилятор вращается свободно.
4.  Проверь, что провода не касаются нагревательного блока.
5.  Включай нагрев только после проверки всех механических узлов.

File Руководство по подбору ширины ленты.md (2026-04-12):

# Руководство по подбору ширины ленты

Главная проблема переработки ПЭТ-бутылок — разная толщина стенок (от 0.2 мм у «мягких» бутылок для воды до 0.4 мм у плотной тары из-под соков или молока). Если лента будет слишком широкой, она не пройдет через сопло или заклинит мотор. Если слишком узкой — филамент получится полым или тоньше 1.75 мм, что приведет к недоэкструзии при печати.

## Таблица расчета (целевой диаметр 1.75 мм)

Используйте эти данные для настройки бутылкореза:

| Толщина стенки бутылки (мм) | Необходимая ширина ленты (мм) |
| --- | --- |
| 0.20 | 12.0 |
| 0.21 | 11.4 |
| 0.22 | 10.9 |
| 0.23 | 10.5 |
| 0.24 | 10.0 |
| 0.25 | 9.6 |
| 0.26 | 9.2 |
| 0.27 | 8.9 |
| 0.28 | 8.6 |
| 0.29 | 8.3 |
| 0.30 | 8.0 |
| 0.31 | 7.8 |
| 0.32 | 7.5 |
| 0.33 | 7.3 |
| 0.34 | 7.1 |
| 0.35 | 6.9 |
| 0.36 | 6.7 |
| 0.37 | 6.5 |
| 0.38 | 6.3 |
| 0.39 | 6.2 |
| 0.40 | 6.0 |

---

## Практические советы по калибровке:

1.  Измерение толщины: Перед нарезкой обязательно измерьте стенку бутылки микрометром или штангенциркулем в нескольких местах. ПЭТ-бутылки часто имеют неравномерную толщину (ближе к дну стенки толще).
2.  Золотое правило: Для большинства стандартных бутылок объемом 1.5–2 литра (толщина ~0.25–0.28 мм) оптимальная ширина ленты составляет 9.0–9.5 мм.
3.  Контроль диаметра: После прохождения первых 50 см ленты через станок, измерьте полученный филамент.

- Если диаметр > 1.78 мм: уменьшите ширину ленты на 0.2–0.3 мм.
- - Если диаметр < 1.70 мм: увеличьте ширину ленты.

4.  Маркировка тары: В рамках образовательного проекта рекомендуется заранее рассортировать бутылки по типам (и толщине) и наносить на бутылкорез метки, соответствующие конкретным брендам напитков.

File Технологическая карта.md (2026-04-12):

# Технологическая карта

## Этапы производства филамента «PET-Мастер»

# 1. Подготовка и сортировка

- Осмотр: Отбор чистых бутылок без внешних дефектов, чистые.
- Сортировка: Некондиция, горлышки и отрезанные донья не выбрасываются, а собираются для передачи на эжемесячные акции раздельного сбора.
- Очистка: Полное удаление этикеток и клеевого слоя (остатки клея могут засорить сопло).

## 2. Подготовка поверхности (Рифтовка)

Для превращения фигурной бутылки в ровный цилиндр применяется метод пневмо-термического выравнивания:

- Накачка: На бутылку накручивается специальная крышка с автомобильным ниппелем (отверстие 14 мм). С помощью насоса создается избыточное давление.
- Термоусадка: Бутылка равномерно прогревается строительным феном (200–250°C) при постоянном вращении. Давление изнутри расправляет пластик, убирая ребра жесткости и изломы.
- Результат: После остывания и сброса давления получается гладкая заготовка, удобная для точной нарезки.

## 3. Нарезка ленты (Модуль «Нож»)

Встроенный в лицевую панель станка нож позволяет настраивать ширину реза с точностью до мм:

- Конструкция: Набор калибровочных дисков разной высоты и лезвие канцелярского ножа.
- Регулировка: Стяжка конструкции производится вручную с помощью эргономичных ручек с вплавленными гайками (быстрая перестройка под разную толщину стенки по таблице).
- Начало реза: У бутылки отрезается дно, делается направляющий надрез, лента заправляется в нож.

## 4. Запуск экструзии

- Заправка: Узкий кончик ленты («хвост») срезается под острым углом около 2 мм, пропускается через холодный нагревательный блок и фиксируется на приемном барабане.
- Прогрев: Включается контроллер температуры. Оптимальный рабочий диапазон для ПЭТ: 210–215°C.
- Старт: При достижении заданной температуры плавным поворотом рукоятки ШИМ-контроллера запускается мотор-редуктор. Скорость настраивается визуально до момента получения стабильного, ровного прутка без рывков.

---

## Преимущества интегрированного ножа

Размещение ножа непосредственно перед нагревательным блоком на одной раме решает главную проблему — перекручивание ленты. Путь от лезвия до сопла минимален, лента подается строго под нужным углом, что исключает заклинивание и обрывы.

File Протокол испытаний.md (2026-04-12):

# Протокол испытаний филамента «PET-Мастер»

Дата: « » 2026 г.

Оператор станка:

Объект испытания: Вторичный ПЭТ-филамент (пултрузионный)

---

## 1. Характеристики исходного сырья

| Тип тары | Цвет | Объем | Примерный выход (м) | Отметка (V) |
| --- | --- | --- | --- | --- |
| Бутыль для воды | Синий / Голубой / Прозрачный | 5 л | 16–17 м | |
| Бутылка ПЭТ | Коричневый (пиво/квас) | 1–2 л | 8–9 м | |
| Бутылка ПЭТ | Белый (молоко) | 0.9–1.5 л | 6–8 м | |
| Бутылка ПЭТ | Черный (энергетик) | 0.5–1 л | 4–6 м | |

---

## 2. Параметры производства (Экструзия)

- Толщина стенки заготовки: мм.
- Установленная ширина ленты: мм.
- Рабочая температура блока: °C (рекомендовано 210–215°C).
- Скорость протяжки (положение ШИМ): %.

---

## 3. Геометрический контроль (ГОСТ Р 59100-2020)

Измерения проводятся штангенциркулем каждые 3 метра нити.

1.  Замер №1: мм.
2.  Замер №2: мм.
3.  Замер №3: мм.
    Средний диаметр: мм (Цель: 1.75 ±0.05 мм).

---

## 4. Тестовая печать (Параметры слайсера)

Внимание: ПЭТ-филамент из бутылок имеет более высокую температуру плавления и полый профиль.

| Параметр | Значение (рекомендуемое) | Значение (факт) |
| --- | --- | --- |
| Температура сопла | 255 – 265 °C (до 300°C)  | |
| Температура стола | 80 – 85 °C | |
| Коэффициент экструзии (Flow) | 130 – 135 % | |
| Скорость печати | 30 – 50 мм/сек | |
| Обдув модели | 0 – 30% | |

---

## 5. Оценка результатов печати (чек-лист)

- Адгезия: Первый слой стабильно держится на столе.
- Межслойная спекаемость: Деталь монолитная, не расслаивается при нагрузке.
- Поверхность: Отсутствие «пузырей» (свидетельствует о хорошей просушке сырья).
- Цвет: Соответствует исходной таре, без признаков деградации (почернения) полимера.

---

## 6. Вывод

Нить соответствует / не соответствует стандартам проекта «PET-Мастер».
Рекомендации:

---

## Подпись ответственного:

## 💡 Памятка волонтеру:

- Тугоплавкость: Помните, что вторичный ПЭТ более вязкий, чем покупной PETG. Если ваш принтер не поддерживает нагрев до 270-300°C, убедитесь, что термобарьер имеет медную вставку или является цельнометаллическим.
- Поток 135%: Не пугайтесь высокого значения потока. Пултрузионная нить — это «свернутая трубочка», внутри которой есть пустота. Увеличение потока компенсирует этот внутренний объем, делая стенки модели прочными.

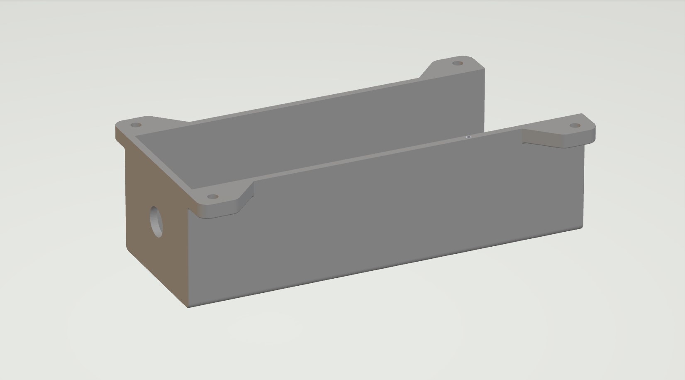
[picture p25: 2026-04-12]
files/img/Вал намотки/Крышка мотор-редуктора.jpg

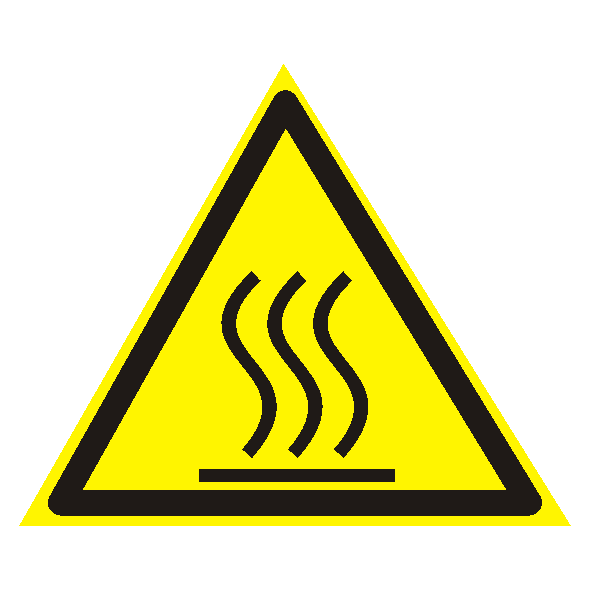
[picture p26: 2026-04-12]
docs/img/CH.png

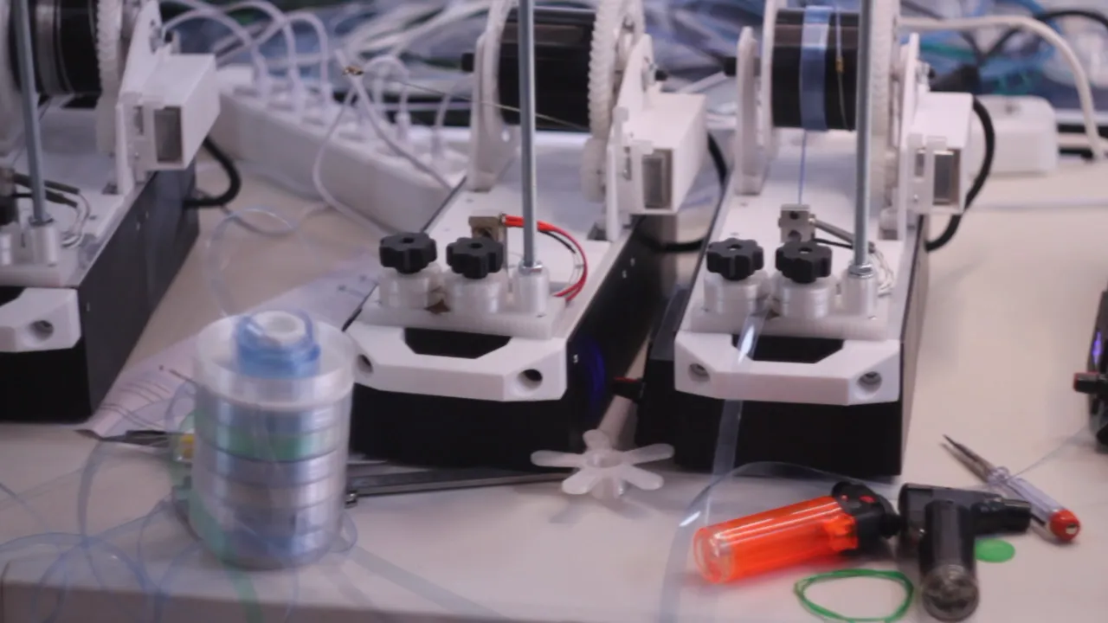
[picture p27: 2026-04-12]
files/img/Процесс сборки станка/Работа станков.webp

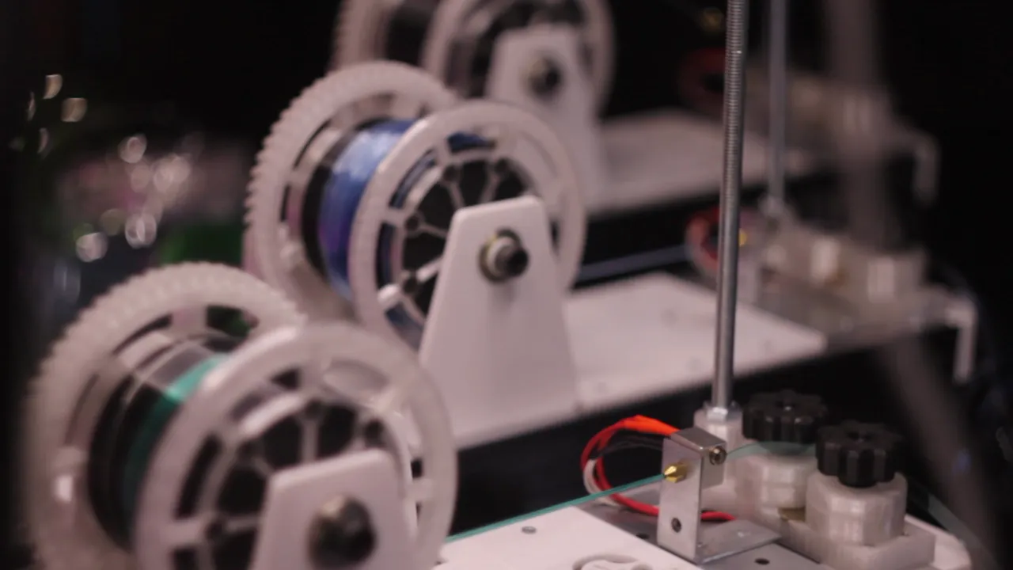
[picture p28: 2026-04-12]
files/img/Процесс сборки станка/крупное фото намотки филамента.webp

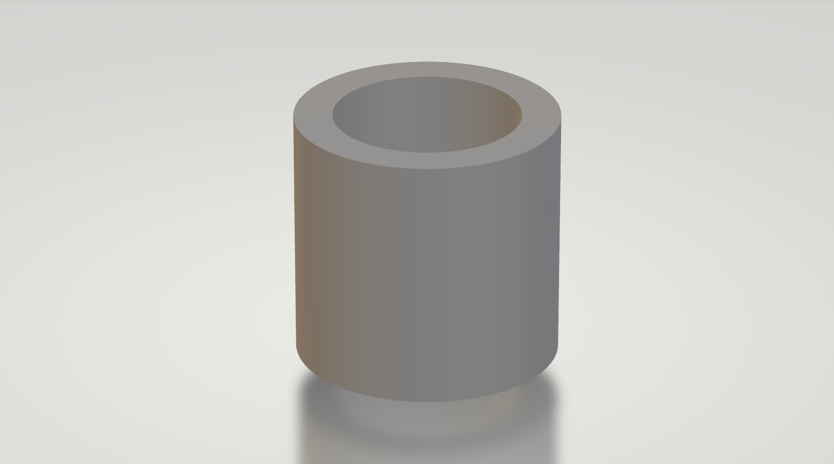
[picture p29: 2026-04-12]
docs/img/Вал намотки/Кольцо барабана намотки.jpg

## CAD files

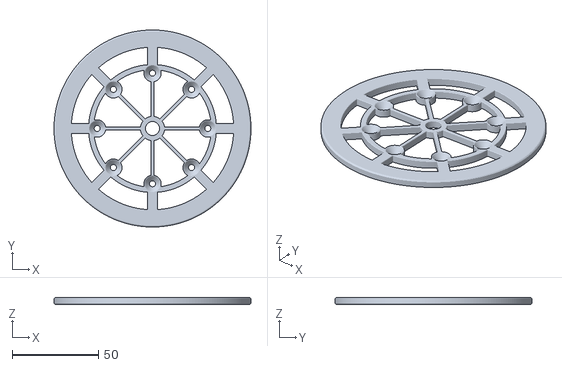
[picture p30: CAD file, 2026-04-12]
models/Вал намотки/Ограничитель намотки.stl
114.0 x 114.0 x 4.00

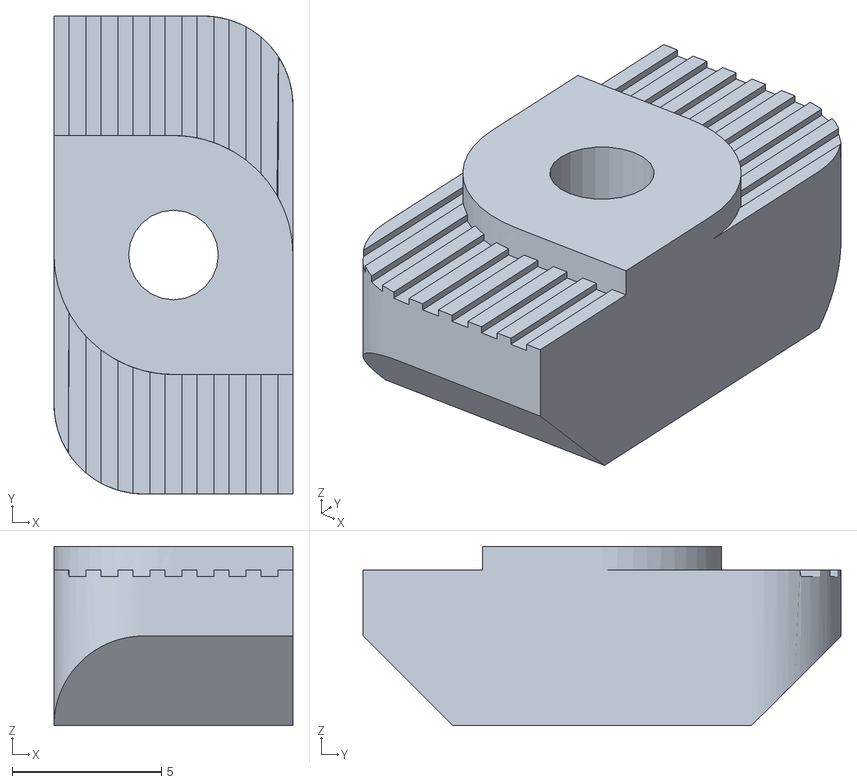
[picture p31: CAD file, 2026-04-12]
models/Основание/Сухарь 30х30 М3 16 шт.stl
8.00 x 16.0 x 6.00

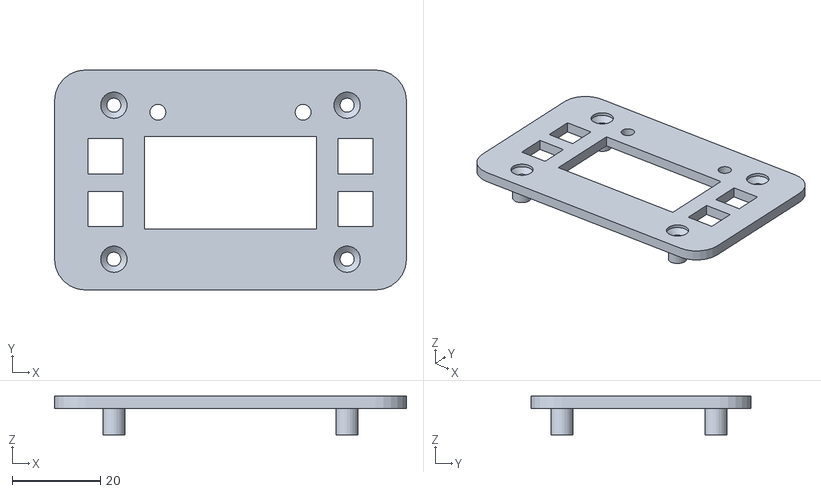
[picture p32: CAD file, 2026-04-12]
models/Электроника/Окно для контроллера H50TR.stl
80.0 x 50.0 x 8.80

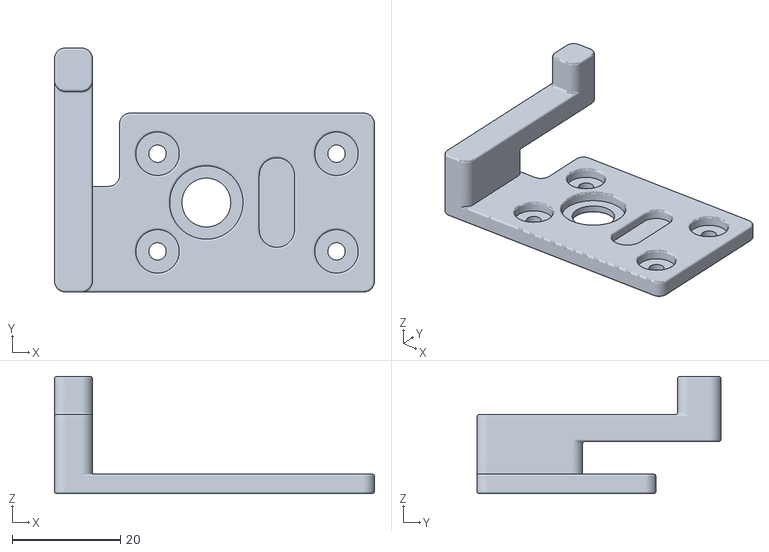
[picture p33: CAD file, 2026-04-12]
models/Вал намотки/Ручка крепления мотора.stl
59.0 x 45.0 x 21.6

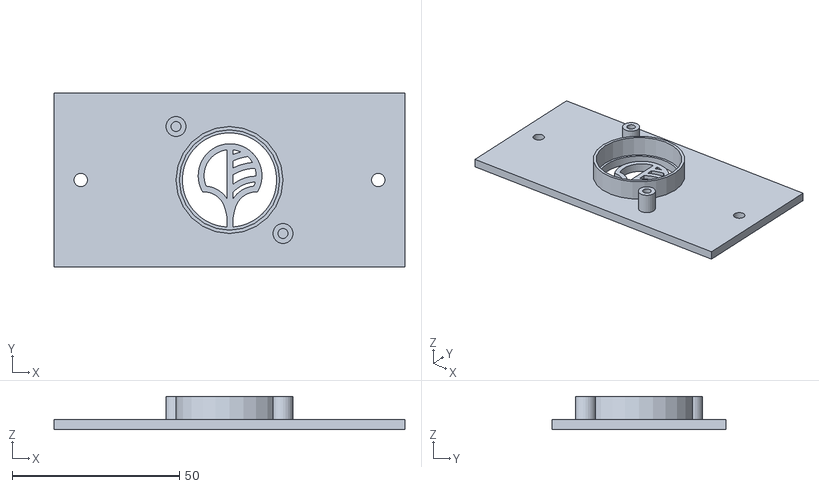
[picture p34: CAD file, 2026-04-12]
models/Основание/Панель охлаждения.stl
105.0 x 52.0 x 10.0

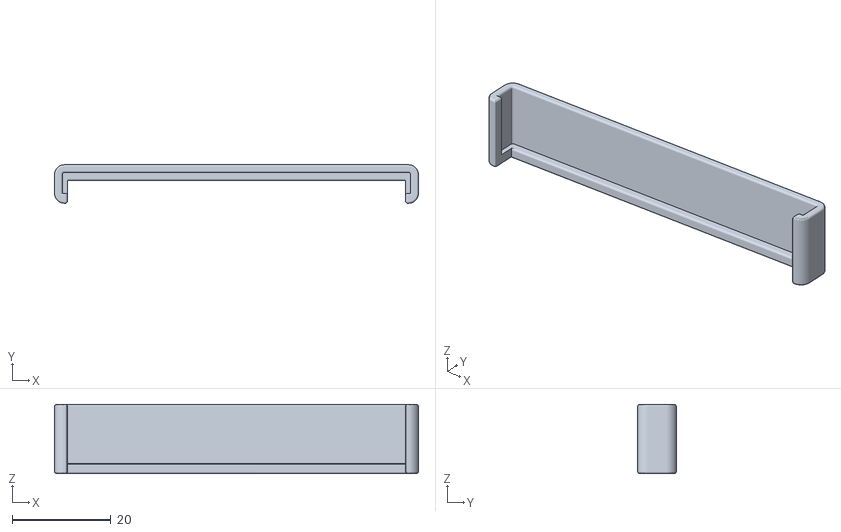
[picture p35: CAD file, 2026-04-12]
models/Электроника/Крышка распределительной коробки.stl
73.6 x 7.80 x 14.0

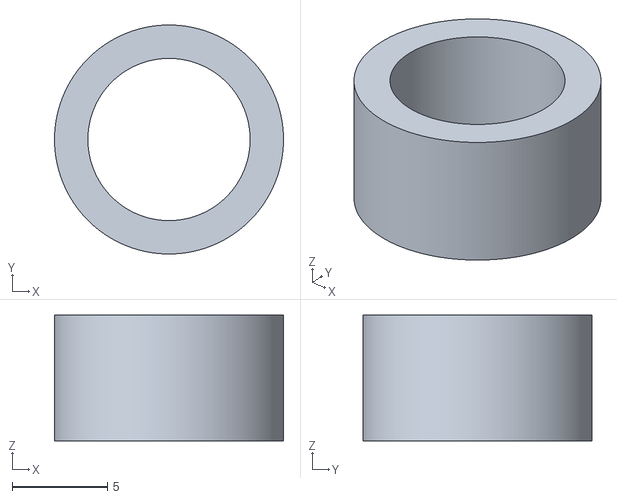
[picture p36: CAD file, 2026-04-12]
models/Вал намотки/Кольцо барабана намотки со стороны мотор-редуктора.stl
12.0 x 12.0 x 6.60

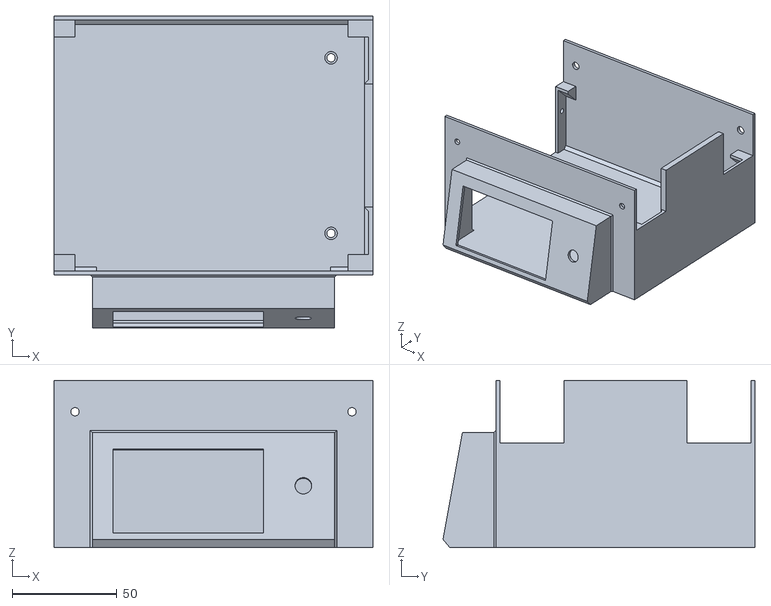
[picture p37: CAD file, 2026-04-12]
models/Основание/Переднее основание.stl
152.5 x 149.3 x 80.0

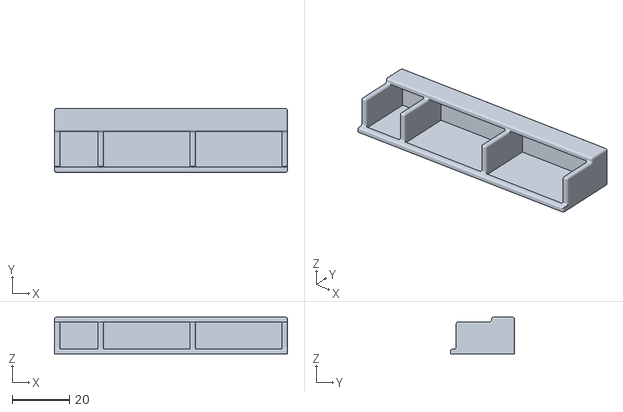
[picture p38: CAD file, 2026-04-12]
models/Электроника/Распределительная коробка.stl
81.6 x 22.4 x 12.8

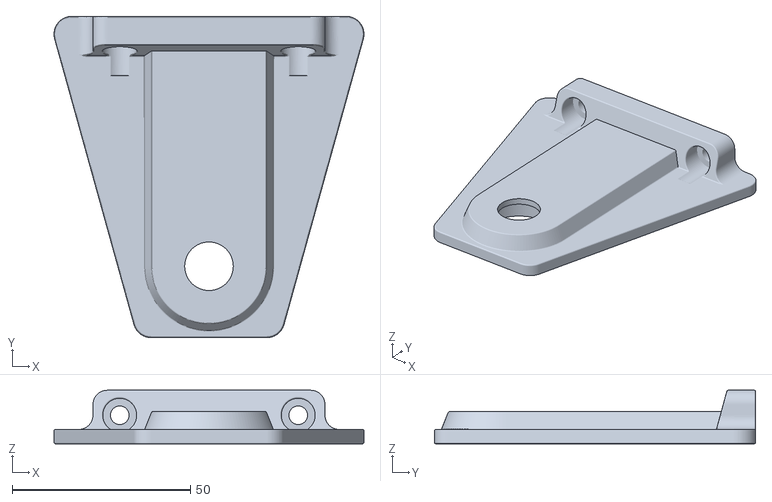
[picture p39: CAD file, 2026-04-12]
models/Вал намотки/Держатель оси.stl
86.8 x 90.0 x 15.0

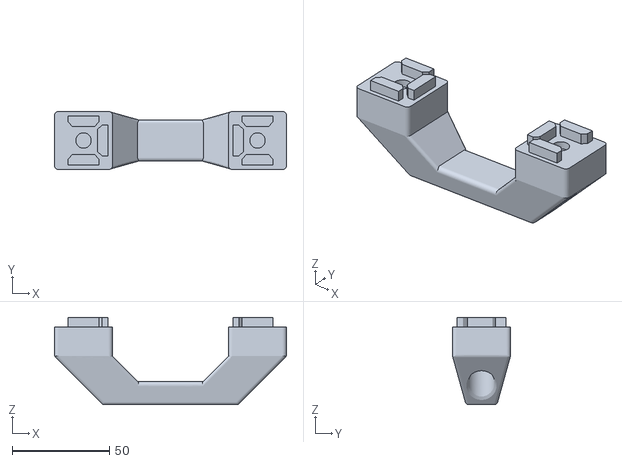
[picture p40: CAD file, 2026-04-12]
models/Основание/Ручка.stl
119.4 x 29.9 x 45.0

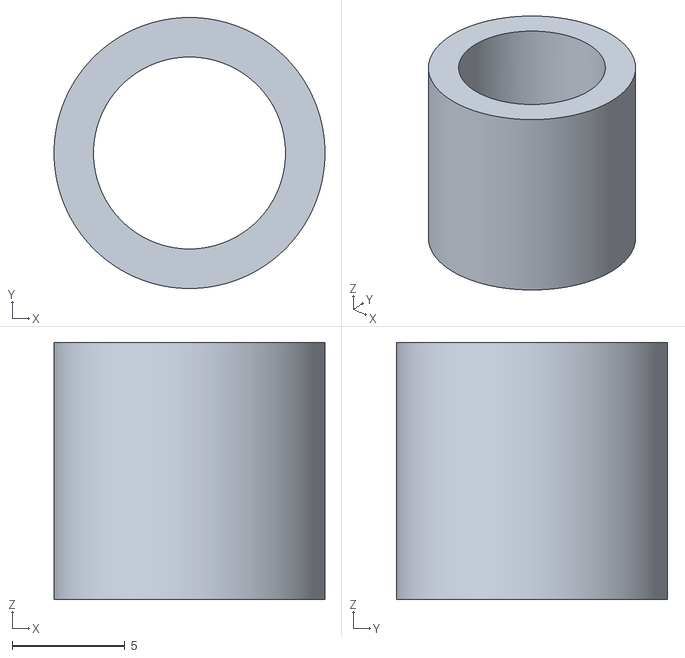
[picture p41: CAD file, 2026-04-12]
models/Вал намотки/Кольцо барабана намотки.stl
12.0 x 12.0 x 11.4

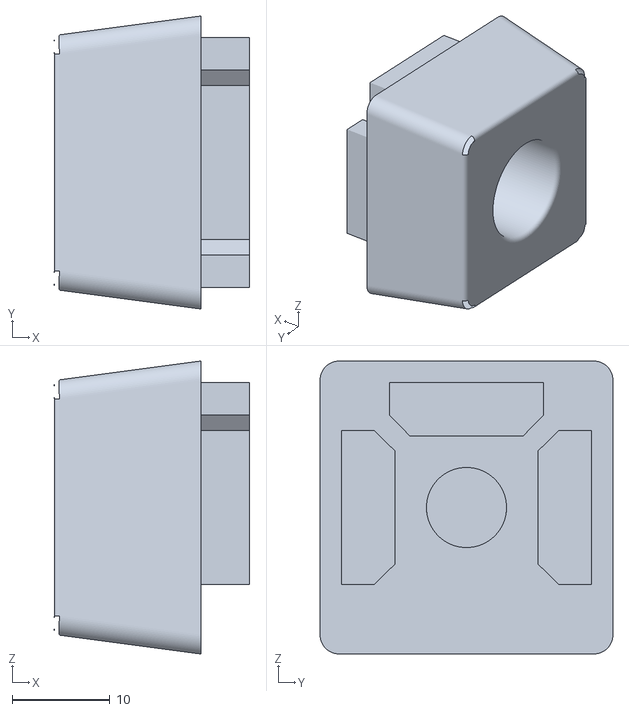
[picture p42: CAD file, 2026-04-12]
models/Основание/Заглушка профиля 2 шт..stl
20.0 x 30.0 x 30.0

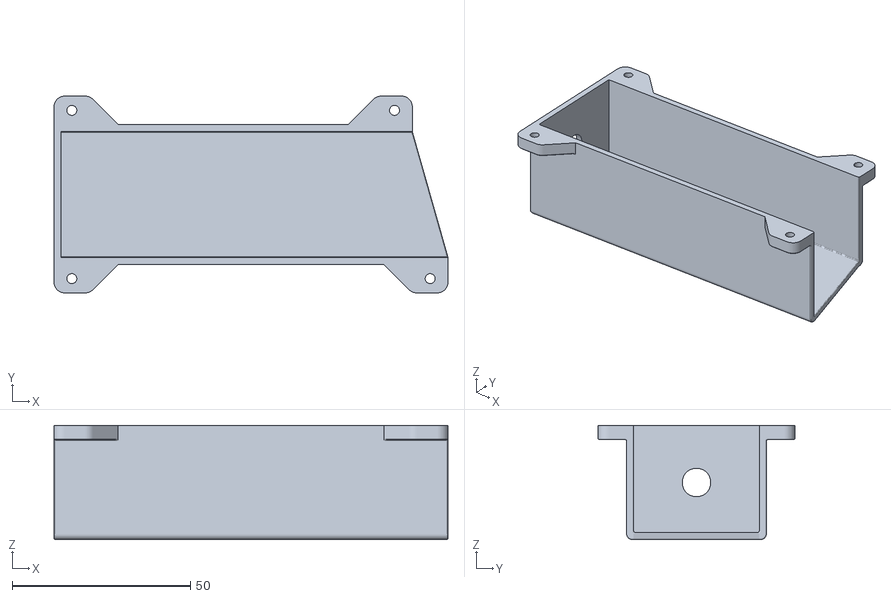
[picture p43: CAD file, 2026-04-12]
models/Вал намотки/Крышка мотор-редуктора.stl
110.5 x 55.2 x 32.0

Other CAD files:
models/Основание/Заднее основание.stl
models/Вал намотки/Цилиндр барабана.stl
models/Вал намотки/Блок фиксации мотора.stl
models/Вал намотки/Прокладка М8 для барабана 2 шт..stl
models/Вал намотки/Основание вала намотки и мотора.stl
models/Вал намотки/Основание фиксации мотора.stl
models/Вал намотки/Ручка блока фиксации мотора.stl

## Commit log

2026-04-12 Описание проекта
2026-04-12 Список оборудования
    [List_hardware_PET_Master.csv]
2026-04-12 Схема подключения
2026-04-12 Протокол испытаний
2026-04-12 Спецификация
2026-04-12 Изображения комплектующих
2026-04-12 Скриншоты моделей
2026-04-12 3D модели
    [air.stl, bearing_plate.3mf, bearing_plate.stl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]
2026-04-12 Документы
2026-04-12 Спуллер
    [spool_side.stl]
2026-04-12 Этапы производства филамента
2026-04-12 Электрическая схема соединений станка
2026-04-12 Список комплектующих
2026-04-12 Руководство по подбору ширины ленты
2026-04-12 Регламент по технике безопасности
2026-04-12 Программа мастер-классов
2026-04-12 Паспорт проекта
2026-04-12 Памятка
2026-04-12 Инструменты
2026-04-12 Инструкция волонтера
2026-04-12 Для грантов
2026-04-12 init docs
    [bearing_plate.3mf, Блок фиксации мотора.stl, Держатель оси.stl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]
2026-04-13 МОУ25
2026-07-07 mobile_nav: гамбургер-меню при max-width 709px, текст навигации сворачивается в иконку с тремя полосками, переключатель темы остаётся видимым
